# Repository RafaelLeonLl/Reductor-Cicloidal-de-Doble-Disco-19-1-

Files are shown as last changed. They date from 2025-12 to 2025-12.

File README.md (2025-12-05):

# Reductor cicloidal 19:1 para motor LA8308 KV90

Este repositorio contiene el diseño geométrico, los modelos CAD, los scripts de cálculo y la documentación del **reductor cicloidal de doble disco 19:1** impreso en PETG, desarrollado para un actuador de rueda de un robot móvil teleoperado.

El diseño original del perfil cicloidal, la selección de parámetros geométricos y los cálculos de verificación mecánica (contacto, flexión y fatiga) fueron realizados por **Rafael Alejandro León Llanllaya** (Universidad Católica de Santa María, Arequipa, Perú).

---

## Contenido del repositorio

La estructura propuesta es la siguiente (puedes ajustarla a tu gusto):

```text
.
├── doc/
│   ├── paper_ieee.tex        # Artículo en formato IEEE
│   ├── paper_ieee.pdf        # PDF de la preimpresión
│   └── notas_diseno.md       # Notas adicionales de diseño
├── cad/
│   ├── disco_cicloidal.SLDPRT
│   ├── conjunto_reductor.SLDASM
│   └── export_step/          # Archivos .step/.iges para intercambio
├── scripts/
│   ├── cicloide_waterloo.m   # Generación del perfil en MATLAB
│   ├── postprocesado.m       # Cálculo de esfuerzos / gráficos
│   └── ...                   # Otros scripts relacionados
├── img/
│   ├── A1.png                # Render CAD del reductor
│   ├── A2.png                # Sección del conjunto reductor-rueda
│   ├── A3.png                # Boceto paramétrico en SolidWorks
│   └── A4.png                # Perfil generado en MATLAB
└── README.md

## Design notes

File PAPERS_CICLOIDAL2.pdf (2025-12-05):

# Borrador Diseño e implementación de un Reductor Cicloidal de Doble Disco 19:1 Impreso en PETG para robot cuadrupedo con un par de hasta 120 Kg.cm

Rafael Alejandro León Llanllaya, Autor 2, Autor 3, Autor 4, Autor 5, Autor 6 Escuela Profesional de Ingeniería Mecatrónica Universidad Católica de Santa María, Arequipa, Perú Email principal: rafael.leon@estudiante.ucsm.edu.pe

Resumen—Este artículo presenta el diseño geométrico, la definición paramétrica y el análisis mecánico de un reductor cicloidal de doble disco, con relación de transmisión 19:1, fabricado en PETG y acoplado a un motor brushless EAGLE POWER LA8308 KV90. Se adopta una formulación paramétrica tipo Waterloo para generar el perfil del disco cicloidal en CAD, y se desarrolla una metodología de cálculo que incluye conversión de torque, distribución de fuerzas en pasadores, verificación por presión de contacto, flexión y fatiga mediante el diagrama de Goodman. El reductor fue concebido, modelado y dimensionado por el autor principal en el marco de un proyecto de actuador de rueda para un robot móvil teleoperado, dejando una base lista para futuras validaciones numéricas y experimentales.
Index Terms—Reductor cicloidal, diseño mecánico, robótica, análisis estructural, torque, fatiga, PETG.
I. INTRODUCCIÓN

Los reductores cicloidales se emplean de forma creciente en aplicaciones robóticas debido a su alta densidad de torque, bajo retroceso (backlash) y buena rigidez torsional, manteniendo un volumen compacto frente a engranajes planetarios o armónicos convencionales [6], [7], [9]. Su principio de funcionamiento se basa en el movimiento excéntrico de uno o más discos cicloidales que engranan con un anillo de pasadores fijos, generando grandes reducciones de velocidad con múltiples puntos de contacto simultáneos.
En la literatura se encuentran trabajos centrados en el modelado paramétrico del perfil cicloidal [3], [4], en el análisis de la distribución de carga y contacto diente–pasador en reductores tipo RV [6], [7], y en aplicaciones robóticas como articulaciones de exoesqueletos o prótesis de rodilla [8]. También existen guías de diseño y validación experimental con prototipos impresos en 3D que muestran el desempeño real de estos reductores frente a versiones maquinadas [5].
Sin embargo, muchos de estos recursos asumen materiales metálicos y procesos de manufactura de alta precisión. En este trabajo se documenta un diseño completo de reductor cicloidal de doble disco, optimizado para impresión en PETG y orientado a un robot móvil teleoperado, con un enfoque de diseño mecánico clásico basado en cálculos de esfuerzos estáticos y de fatiga siguiendo los criterios propuestos por Shigley y Norton [1], [2].
Los objetivos principales son:
Presentar un marco teórico compacto y referenciado sobre reductores cicloidales y su uso en robótica. Detallar una metodología reproducible para el diseño geométrico y mecánico de un reductor cicloidal de doble disco 19:1 impreso en PETG.
Definir y documentar un plan de validación estructural basado en análisis por elementos finitos (FEA) y ensayos experimentales del prototipo impreso.

II. MARCO TEÓRICO DEL REDUCTOR CICLOIDAL

II-A. Principio de funcionamiento
Un reductor cicloidal está formado típicamente por: (i) un eje de entrada excéntrico, (ii) uno o dos discos cicloidales, (iii) un anillo de pasadores (o rodillos) fijos a la carcasa y (iv) pasadores de salida que transmiten el movimiento del disco a la brida de salida [7], [9]. Cuando el eje de entrada gira, el desplazamiento excéntrico hace que el disco cicloidal describa un movimiento de rodadura relativa sobre el anillo de pasadores, produciendo una rotación lenta en sentido opuesto. Si el anillo tiene N pasadores y el disco posee N−1 lóbulos, la relación de transmisión ideal es aproximadamente

i ≈

N
N − 1
= 1 : (N − 1), | (1)

por lo que, para N = 20, se obtiene i ≈ 1 : 19. En la práctica el uso de dos discos desfasados 180◦ permite reducir vibraciones y suavizar el par transmitido [4], [5].

II-B. Formulaciones paramétricas
El perfil externo del disco cicloidal puede modelarse como una cicloide contraída, tal como se desarrolla en trabajos de modelado paramétrico de Petrovic [3] y en guías técnicas ´ recientes [4], [5]. En este trabajo se adopta la formulación difundida por la Universidad de Waterloo, basada en las variables R, Rr, E y N, que se detalla en la Sección III-B.

Cuadro I
PARÁMETROS DE ENTRADA DEL DISEÑO
Parámetro | Valor
Radio de paso del anillo, R | 37.5 mm
Radio del pasador, Rr | 4 mm (dpin = 8 mm)
Número de pasadores, N | 20
Excentricidad del disco, E | 1.2 mm
Espesor del disco, B | 5 mm
Pasadores en carga, nc | 2
Luz efectiva del pasador, Lp | 10 mm
Par requerido, Treq | 120 kg cm
Resistencia PETG, σb | 45 MPa
Resistencia última, Sut | 45 MPa
Límite de fatiga, Se | 0,25Sut = 11,25 MPa

II-C. Distribución de carga y contacto

Análisis modernos usan modelos de contacto no lineales para estimar la distribución de fuerzas entre el disco y los pasadores, así como los campos de tensión en el material [6], [7]. Estos estudios muestran que el número de pasadores en contacto, la excentricidad y la holgura influyen de forma significativa en el factor de seguridad frente a pitting y desgaste.
En este artículo se utiliza un modelo simplificado pero conservador: se supone que solo nc pasadores comparten la carga (típicamente nc = 2–3), y se verifica que la presión de contacto y el esfuerzo de flexión se mantienen por debajo de los límites admisibles del PETG, incorporando además un análisis de fatiga con el diagrama de Goodman [1], [2].

II-D. Aplicaciones robóticas

Reductores cicloidales se han aplicado en articulaciones para exoesqueletos, prótesis de rodilla y robots industriales, gracias a su alta densidad de torque y baja holgura [7], [8]. En robótica móvil, su uso se ha popularizado en actuadores de rueda compactos y estructuras de locomoción de alta carga.

III. METODOLOGÍA DE DISEÑO DEL REDUCTOR

PROPUESTO

En esta sección se describe el procedimiento seguido para el diseño de un reductor cicloidal de doble disco con relación 19:1, orientado al motor LA8308 KV90. Se adopta un torque de diseño Treq = 120 kg cm, que incluye un margen sobre el torque continuo del motor.

III-A. Datos de entrada del diseño

Los parámetros geométricos y de material se resumen en la Tabla I.

III-B. Ecuaciones paramétricas del disco cicloidal

Siguiendo la formulación Waterloo [4], se definen:

k = 1 − N, | (2)

A =

R
EN
. | (3)

Las coordenadas del perfil (en milímetros) son: X(t) = R cost − Rr cos
t + tan⁻¹

sin(kt)
A − cos(kt)
− E cos(N t),

(4)
Y (t) = −R sin t + Rr sin t + tan⁻¹

sin(kt)
A − cos(kt)
+ E sin(N t).

(5)

Para este diseño:

k = 1 − 20 = −19, | (6)

A =

37,5
1,2 · 20
= 1,5625. | (7)

Estas ecuaciones se implementan en MATLAB o SOLID-WORKS como curva impulsada por ecuación, generando el contorno 2D que luego se extruye hasta el espesor B. El segundo disco cicloidal se obtiene defasado 180◦ para reducir desbalanceos [4], [5].

III-C. Conversión de torque y fuerza en los pasadores
Se convierte el par a unidades del SI. Usando 1 kg cm = 0,0980665 N m:
Treq = 120 kg cm = 120 · 0,0980665 ≈ 11,77 N m, | (8)
Treq ≈ 1,18 × 10⁴ N mm. | (9)

El brazo efectivo del par sobre el disco se aproxima como

Reff = R − E = 37,5 − 1,2 = 36,3 mm. (10)

La fuerza tangencial total en el anillo es

Ft =

Treq

Reff

≈

1,18 × 10⁴
36,3

≈ 3,24 × 10² N. (11)

Suponiendo nc = 2 pasadores en contacto:

Fpin =

Ft
nc

≈

324
2
≈ 1,62 × 10² N. | (12)

III-D. Presión de contacto pasador–disco
Se aproxima el área de contacto como un rectángulo de base 2Rr y altura B:

ppin =

Fpin
2RrB
. | (13)

Con Rr = 4 mm y B = 5 mm:

Ac = 2RrB = 2 · 4 · 5 = 40 mm²
, | (14)

ppin =

162
40
≈ 4,05 MPa. | (15)

Como criterio de diseño se adopta una presión admisible

padm = 0,4 σb = 18 MPa, | (16)

por lo que el factor de seguridad frente a presión es

F Sp =

padm

ppin

≈

18
4,05
≈ 4,44. | (17)

El par máximo admisible limitado por presión resulta

Tm´ax,p = F Sp Treq ≈ 4,44 · 120 ≈ 5,3 × 10²
kg cm. (18)

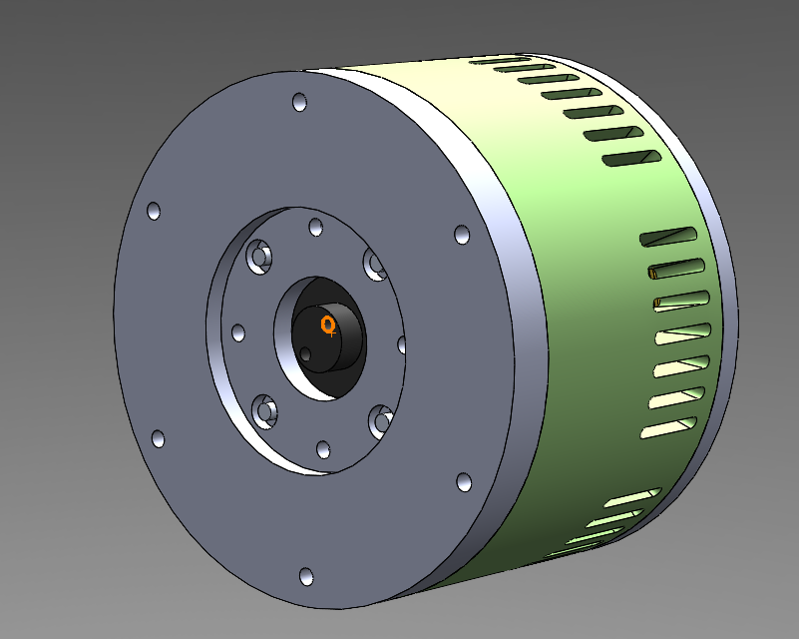
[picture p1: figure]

Figura 1. Modelo CAD final del reductor cicloidal de doble disco 19:1 diseñado por el autor principal. Fuente: elaboración propia.

III-E. Flexión y fatiga en el pasador

Modelando cada pasador como viga simplemente apoyada de luz Lp cargada en el centro, el momento flector máximo es

Mmax =

FpinLp
4
. | (19)

Con Fpin ≈ 162 N y Lp = 10 mm:

Mmax ≈

162 · 10
4
≈ 4,05 × 10² N mm. | (20)

Para un pasador de diámetro dpin = 8 mm, el momento de inercia y el módulo resistente son:

I =

πd⁴
pin
64

=

π(8)⁴
64

= 64π ≈ 2,01 × 10² mm⁴
, (21)

c =

dpin
2
= 4 mm. | (22)

El esfuerzo máximo de flexión:

σmax =

Mmaxc
I

≈

405 · 4
2,01 × 10²

≈ 8,1 MPa. (23)

Suponiendo un ciclo de 0 a σmax, el esfuerzo alternante y el medio son:

σa = σm =

σmax
2
≈ 4,0 MPa. | (24)

Aplicando el criterio de Goodman [1], [2]:

F SGoodman =

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
11,25

+

4,0
45

≈ 2,2. (25)

El par máximo por fatiga es:

Tm´ax,fat = F SGoodman Treq ≈ 2,2·120 ≈ 2,7×10² kg cm. (26)

El límite global viene dado por el más restrictivo:

Tm´ax,global = m´ın (Tm´ax,p, Tm´ax,fat) ≈ 2,7×10²
kg cm. (27)

Para el par de diseño Treq = 120 kg cm se obtienen factores de seguridad aproximados:

F Sp ≈ 4,4, | F SGoodman ≈ 2,2.

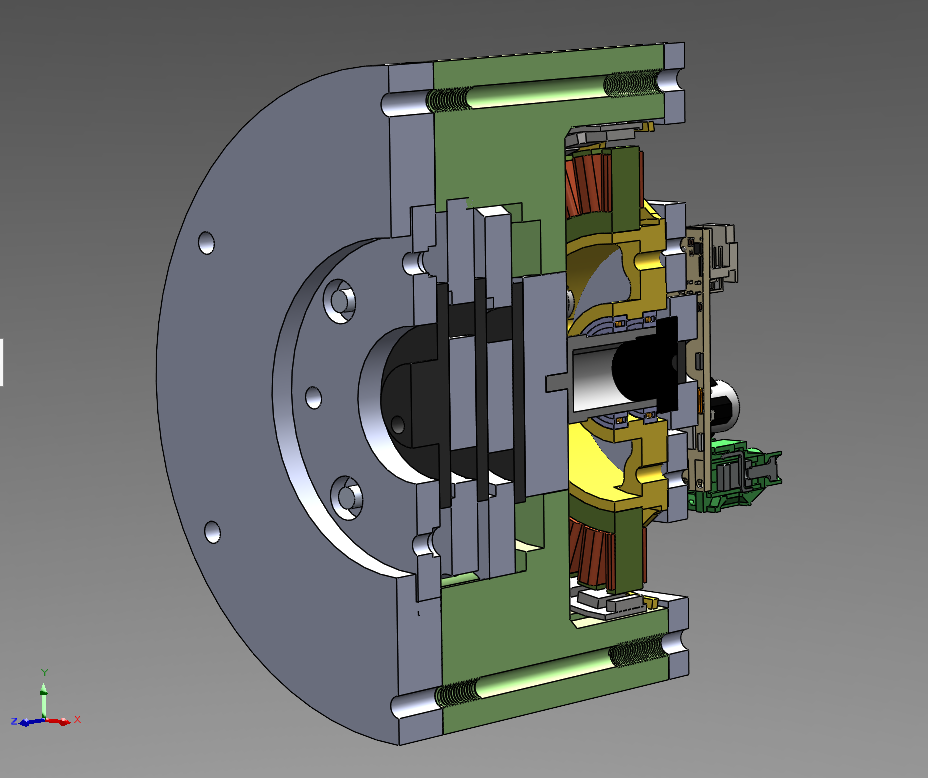
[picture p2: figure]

Figura 2. | Sección del conjunto reductor–rueda para visualización de la
integración mecánica. Fuente: elaboración propia.

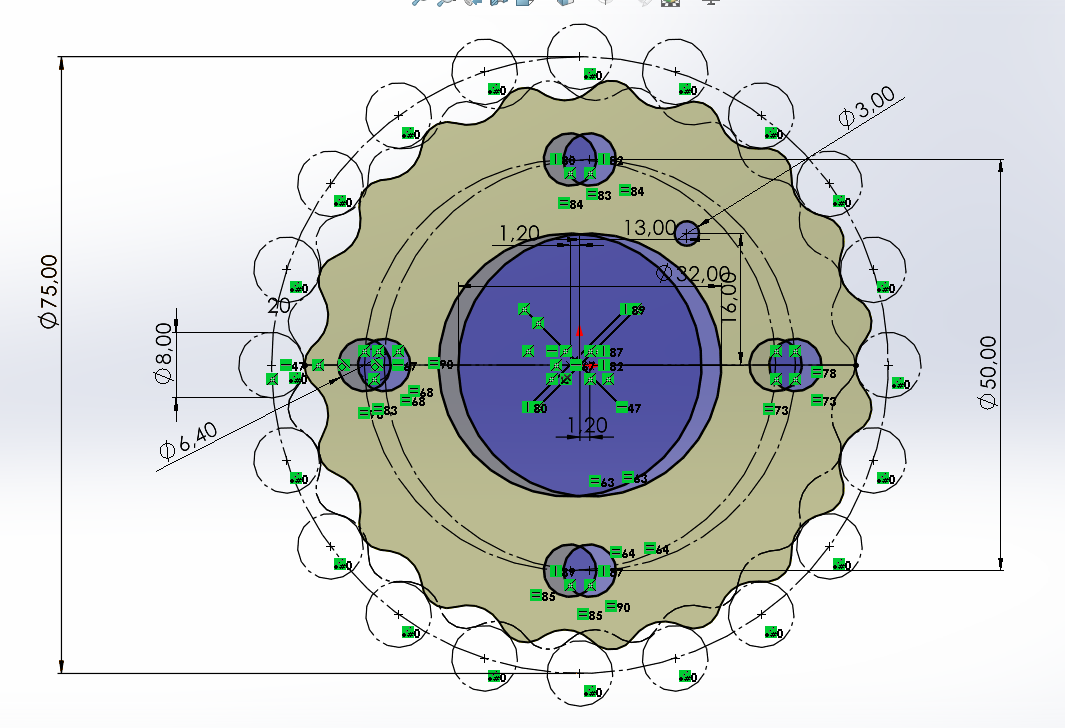
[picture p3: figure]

Figura 3. Boceto paramétrico del disco cicloidal en SolidWorks obtenido a partir de las ecuaciones de Waterloo. Fuente: elaboración propia.

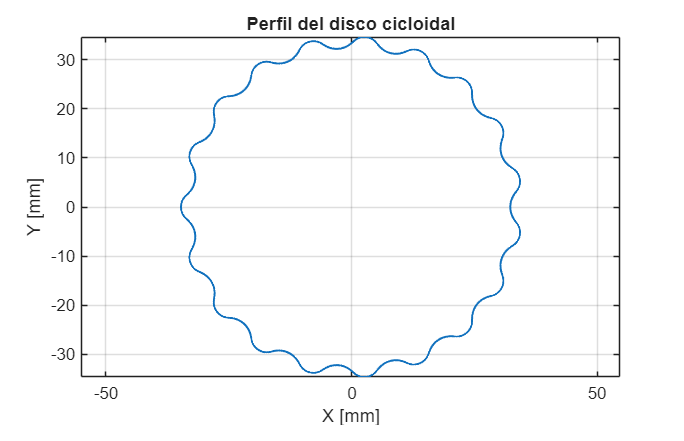
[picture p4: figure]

Figura 4. Previsualización del perfil cicloidal generada en MATLAB con los parámetros del diseño propuesto. Fuente: elaboración propia.

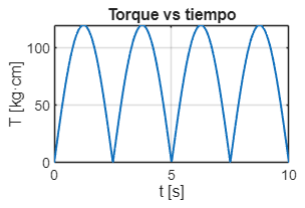
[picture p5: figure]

Figura 5. Evaluación del torque en el reductor cicloidal con respecto al tiempo durante un interval de 10 segundos generada en MATLAB con los parámetros del diseño propuesto. Fuente: elaboración propia.

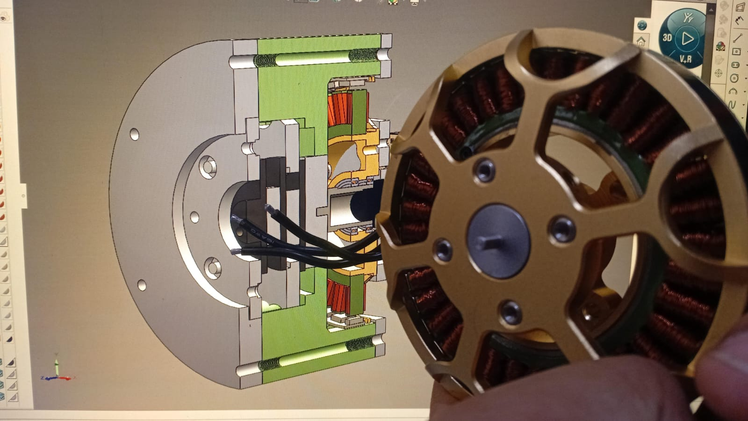
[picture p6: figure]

Figura 6. Visualización de Eaglepower LA8308 KV90 con ensamble final Fuente: elaboración propia.

IV. MODELO CAD Y GENERACIÓN DEL PERFIL
Para el diseño del cicloide en CAD se utilizó la herramienta de ecuaciones de SolidWorks (licencia académica), implementando directamente las expresiones de la Sección III-B. El perfil generado se verificó previamente en MATLAB mediante una nube de puntos y la visualización del contorno completo.
V. PLAN DE VALIDACIÓN Y RESULTADOS ESPERADOS
En coherencia con el tercer objetivo, en esta sección se plantea un esquema de validación estructural que combina análisis numérico por elementos finitos (FEA) y ensayos experimentales sobre el prototipo impreso. El detalle cuantitativo de cada etapa se documentará a medida que se ejecuten las pruebas.

V-A. Modelo de elementos finitos

V-B. Prototipos impresos en PETG

V-C. Ensayos experimentales de torque y backlash

VI. CONCLUSIONES Y TRABAJO FUTURO

AGRADECIMIENTOS
El autor principal agradece el soporte académico de la Escuela Profesional de Ingeniería Mecatrónica de la Universidad Católica de Santa María. Asimismo, declara que el diseño mecánico, los modelos CAD y los cálculos estructurales del reductor cicloidal presentados en este artículo son de su autoría y forman parte de un trabajo original de investigación en curso, en colaboración con los coautores para las etapas de integración y validación experimental.

REFERENCIAS

[1] R. G. Budynas and J. K. Nisbett, Shigley’s Mechanical Engineering Design, 10th ed. New York, NY, USA: McGraw-Hill, 2015.
[2] R. L. Norton, Machine Design: An Integrated Approach, 6th ed. Upper Saddle River, NJ, USA: Prentice Hall, 2019.
[3] N. Petrovic, S. Pavlovi ´ | c, and M. Bošnjak, “Parametric modeling of a ´
cycloid drive relative to the input shaft angle,” in Proc. Int. Conf. Mech. Eng., 2015.
[4] A. T. Huang, “Cycloidal drive – Rev 1 prototype journal,” Univ. of Waterloo Robotics Design Team, internal online report, May 2021.
[Online]. Available: https://uwaterloo.atlassian.net/...
[5] D. Nedelkovski, “CNC Machined vs 3D Printed Cycloidal Drive – Designing & Testing,” HowToMechatronics, 2021. [Online]. Available:
https://howtomechatronics.com/...
[6] X. Li, L. Tang, H. He, and L. Sun, “Design and load distribution analysis of the mismatched cycloid-pin gear pair in RV speed reducers,” Machines, vol. 10, no. 8, art. 672, 2022.
[7] L. Qi, D. Yang, B. Cao, Z. Li, and H. Liu, “Design principle and numerical analysis for cycloidal drive considering clearance, deformation, and friction,” Alexandria Eng. J., vol. 91, pp. 403–418, 2024.
[8] M. Al Kouzbary, H. Al Kouzbary, J. Liu, and T. Khamis, “Robotic knee prosthesis with cycloidal gear and four-bar mechanism optimized using particle swarm algorithm,” Actuators, vol. 11, no. 9, p. 253, 2022.
[9] “Cycloidal drive,” Wikipedia, The Free Encyclopedia, accessed Dec. 2025.

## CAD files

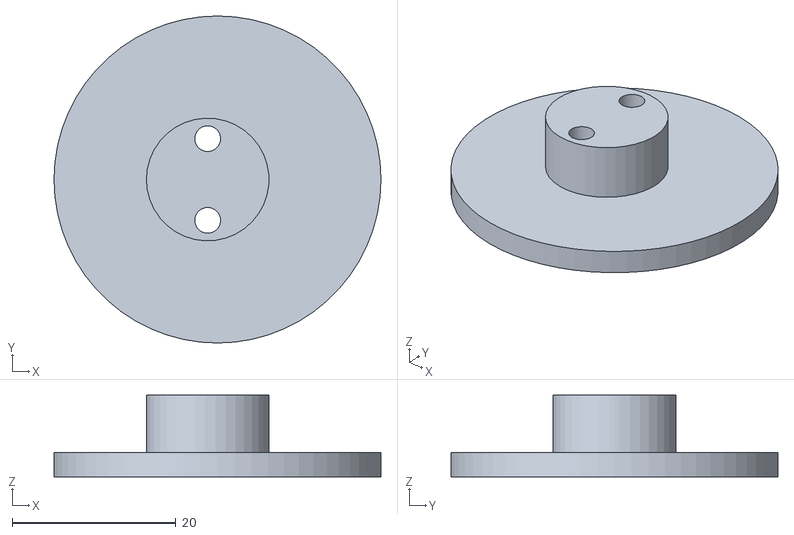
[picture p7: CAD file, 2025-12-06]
separador excentrico 3.STL
40.0 x 40.0 x 10.00

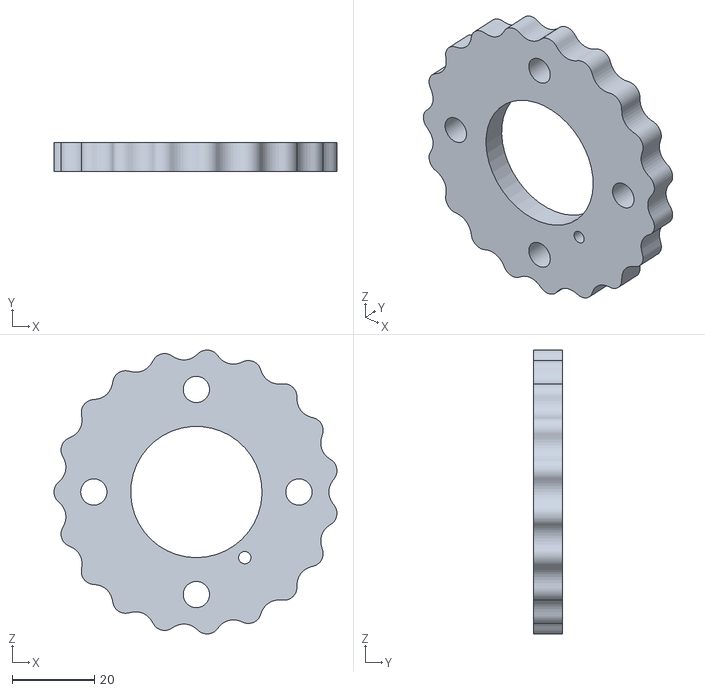
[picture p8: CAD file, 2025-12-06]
Cicloide 2 v3.STL
69.0 x 7.00 x 69.2

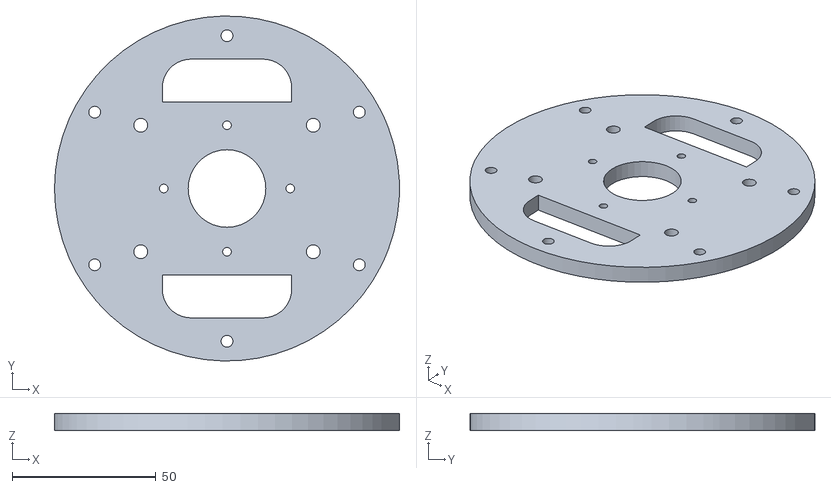
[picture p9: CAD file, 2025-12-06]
Tapa exterior trasera.STL
120.0 x 120.0 x 6.00

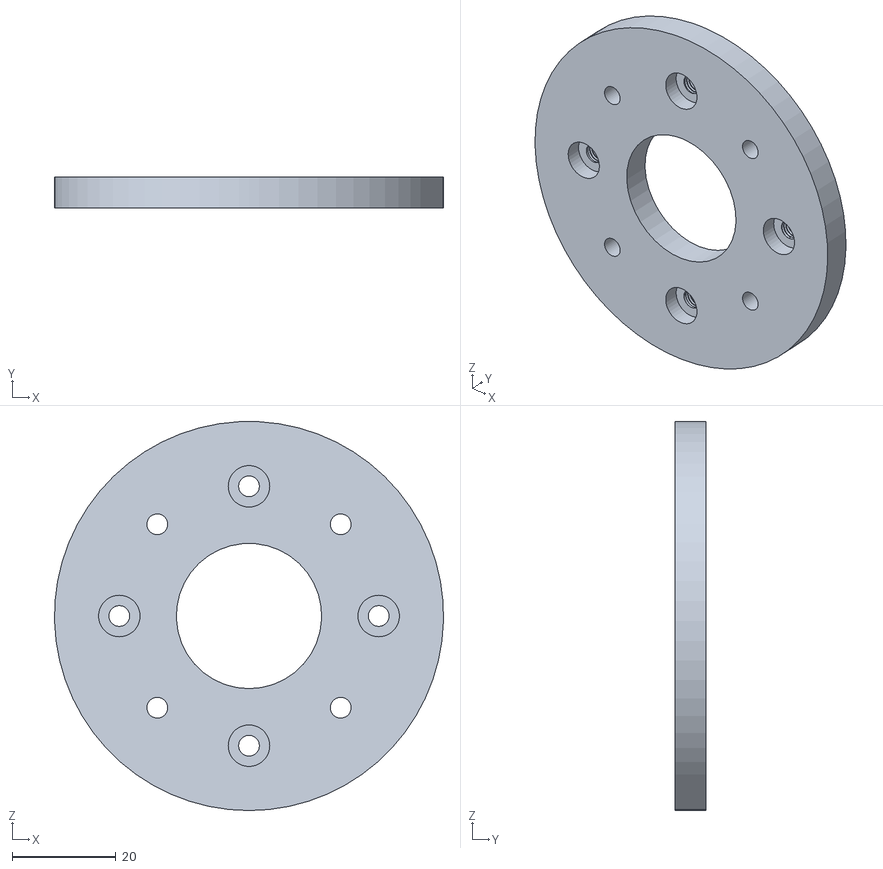
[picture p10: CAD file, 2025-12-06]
TAPA DE SALIDA.STL
75.0 x 6.00 x 75.0

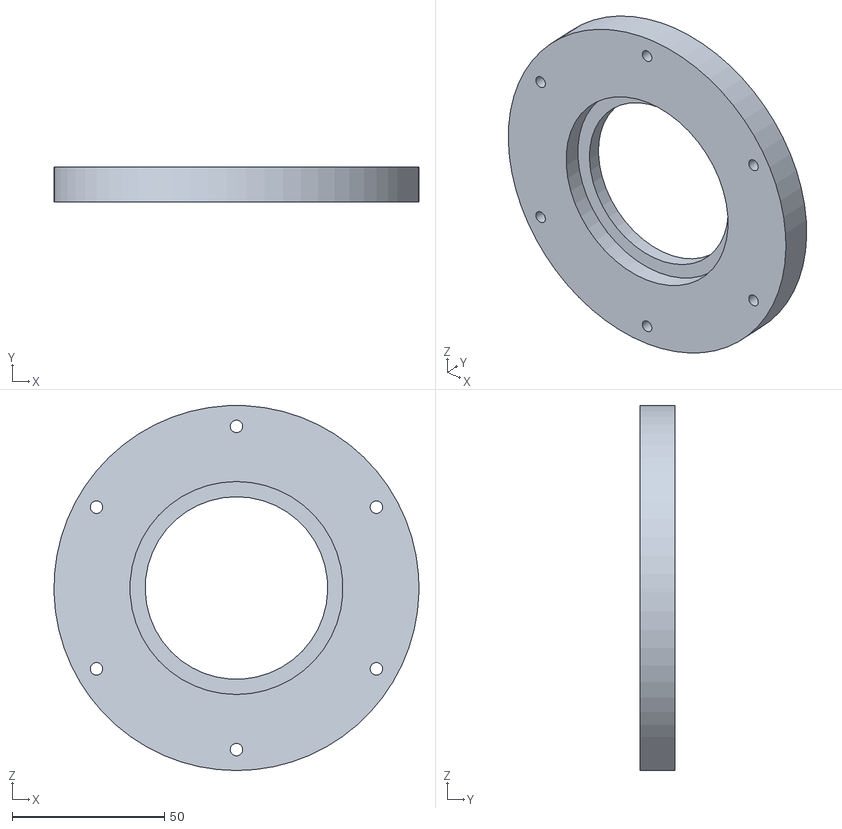
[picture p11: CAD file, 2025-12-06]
Tapa de salida Fija.STL
120.0 x 11.5 x 120.0

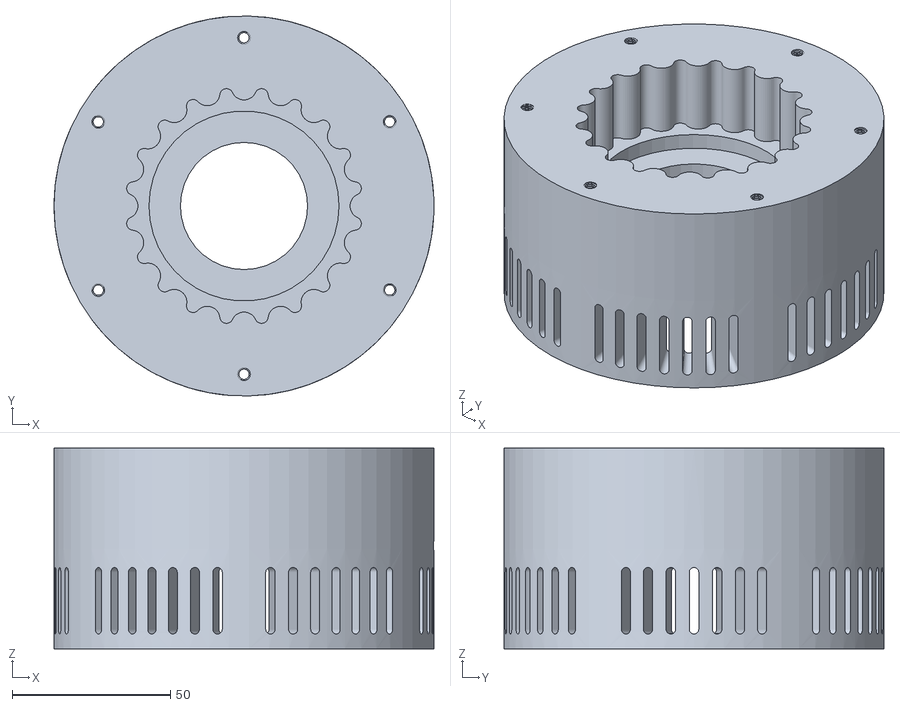
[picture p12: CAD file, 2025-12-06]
Anillo fijo X1.STL
120.0 x 120.0 x 63.4

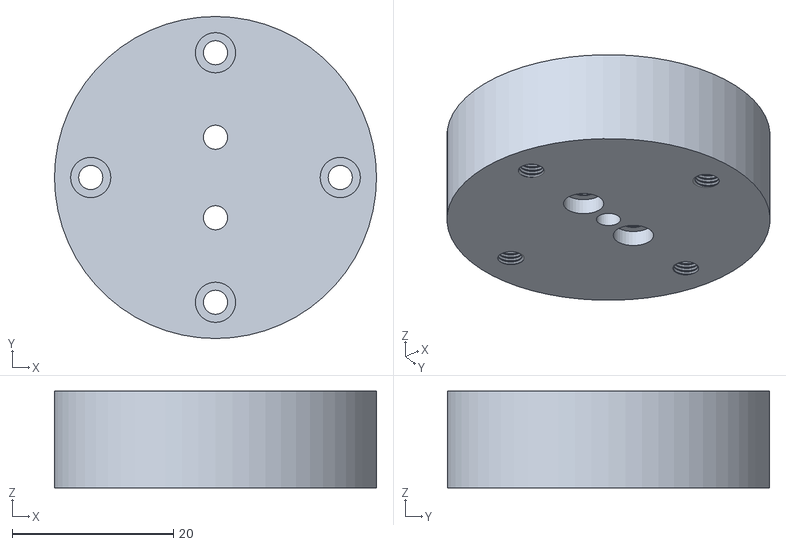
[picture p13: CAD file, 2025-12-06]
Eje entrada.STL
40.0 x 40.0 x 12.0

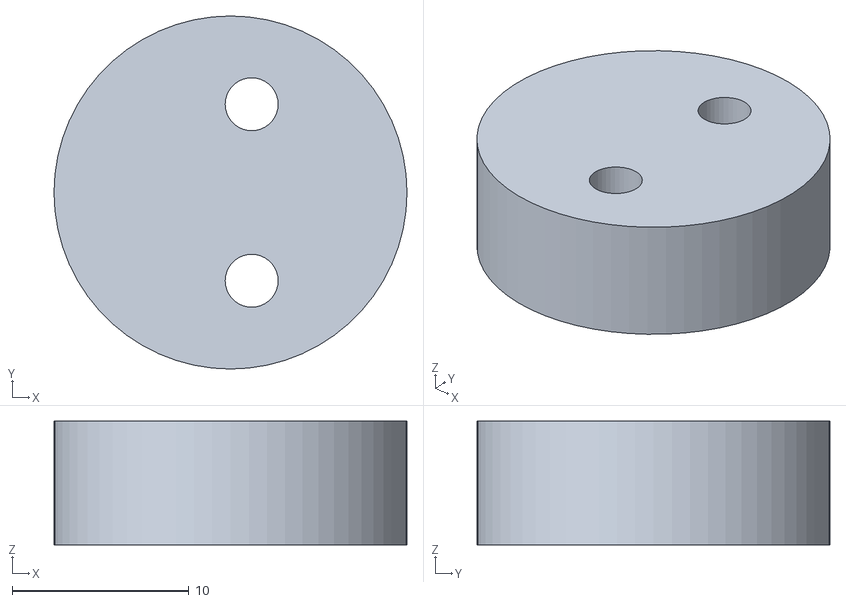
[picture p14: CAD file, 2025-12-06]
Eje excentrico 1.STL
20.0 x 20.0 x 7.00

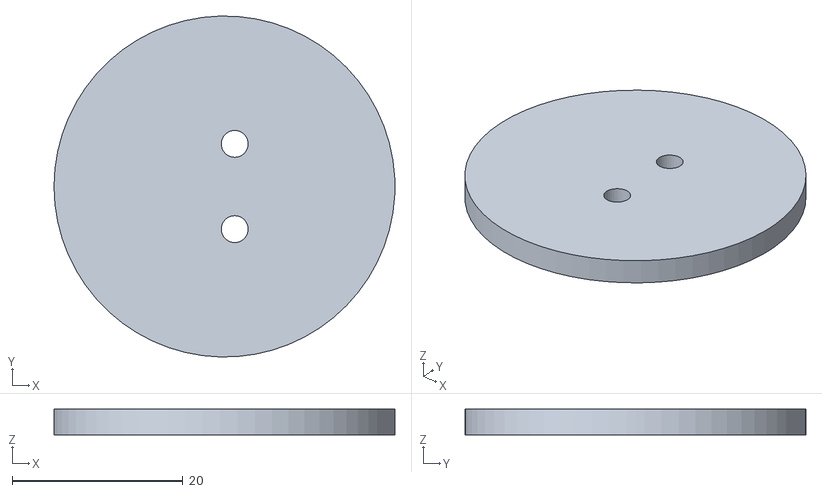
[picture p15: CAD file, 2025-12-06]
Separador exentrico 1.STL
40.0 x 40.0 x 3.00

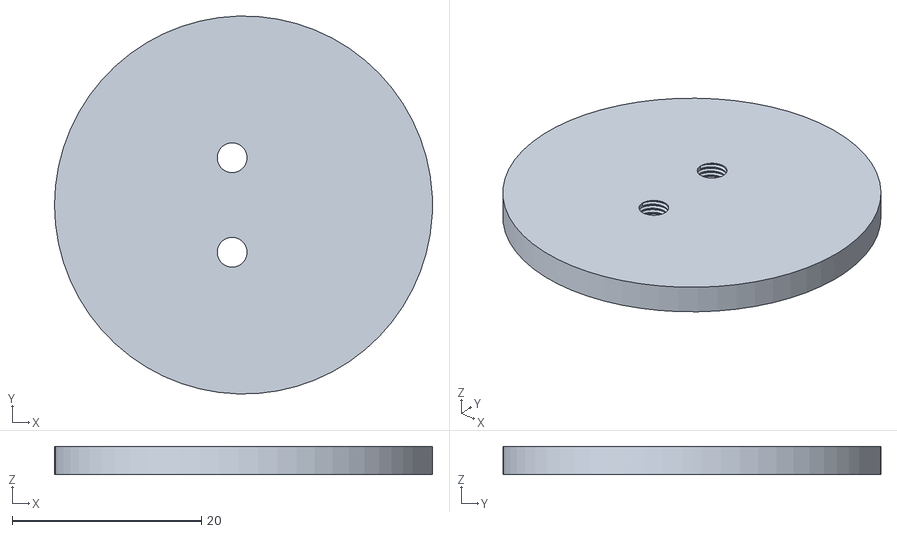
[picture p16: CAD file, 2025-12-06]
separador excentrico 2.STL
40.0 x 40.0 x 3.00

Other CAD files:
Eje excentrico 2.STL
Cicloide 1 v2.STL
